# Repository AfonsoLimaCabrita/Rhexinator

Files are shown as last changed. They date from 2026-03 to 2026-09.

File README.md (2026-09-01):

# Rhexinator — 3D-Printed Capsulorhexis Training Simulator

**Rhexinator** is a 3D-printed training model for practicing **continuous curvilinear capsulorhexis (CCC)** mechanics and cataract-style instrument ergonomics using a replaceable **film “capsule”**. The model is designed to provide realistic approach constraints (face/orbit/temporal and superior approach), a repeatable anterior-chamber working space, and **wound-based pivoting** via corneal incisions.

> **License:** CC0-1.0 (public domain dedication)  
> **Intended use:** training/education only (not a medical device)

---

## This project represents a collaborative work by:

- **Ophthalmology department, Unidade Local de Saude Santa Maria**
- **Faculdade de Medicina da Universidade de Lisboa**
- **Ophthalmology department, Unidade Local de Saude Sao Jose**
- **Universidade de Coimbra Faculdade de Medicina**
- **Universidade Nova de Lisboa Medical School**
- **Mass. Eye and Ear**

---

## What’s in this repository

Current printable parts (STL):

- `Face v6.stl` — upper half of the face/orbit housing  
- `Eye support v8.stl` — socket adapter / support that seats in the orbit and clamps the film  
- `Eye v10.stl` — eye module with iris + cornea + corneal incisions  
- `Stick v3.stl` — plunger/stick used to set eye height within the face (exposure/working depth)

---

## Bill of materials

- 3D-printed parts only (no screws required)
- **Consumable film sheet** (capsule surrogate), placed between the support and the eye module

### Film material (capsule surrogate)
Use a **thin, cellofane, flexible craft film sheet** (pre-cut square sheets). It is typically smooth/glossy, compliant under tension, and will generally **propagate a tear from a starter nick**, making it suitable for repeated CCC tear-control practice when clamped evenly.

**Handling tips**
- Aim for **uniform circumferential tension** (no slack/wrinkles over the working zone).
- If initiation is difficult: create a starter nick with a cystotome.

---

## Recommended print materials

- **TPU 95A:**  
  - `Eye v9.stl`  
  - `Eye support v3.stl`

- **PLA:**  
  - `Face v5.stl`  
  - `Plunger v2.stl`

All parts are designed for **friction-fit assembly** (no hardware).

### Baseline print settings (starting points)
These are generic starting points—tune to your printer/material.

### PLA (Face, Stick)
- Layer height: **0.20 mm**
- Perimeters/walls: **2**
- Infill: **15–25%**
- Supports: **None**

### TPU 95A (Eye, Eye support)
- Print speed: **Slow** (TPU-appropriate)
- Layer height: **0.20 mm / 0.08mm (For top surface of Eye support)**
- Seam: **Opposite to corneal incision**
- Surface pattern: **Circular** (all surfaces)
- Perimeters/walls: **4** (for durable edges)
- Retraction: **1.5 mm**
- Supports: **None**
---

## Assembly

### 1) Seat the support in the orbit
- Press `Eye support v3.stl` into the socket area of `Face v5.stl`.

### 2) Place the film (critical)
- Cut a small section of the square sheet of film and lay it **flat over the support**, centered.

### 3) Install the eye module (clamps the film)
- Press `Eye v9.stl` into the support so the film is **captured and tensioned** between:
  - **Support (below)** and **Eye module (above)**

Check that the film is taut across the working zone with minimal wrinkling.

### 4) Set eye height
- Use `Stick v2.stl` (plunger) to adjust the **height of the eye within the face**, tuning exposure/working depth.

---

## How to use (technique notes)

### Corneal incisions
The **rectangular incisions in the cornea** are meant to be used ports:
- Insert cystotome or capsulorhexis forceps through the rectangular ports into the anterior chamber.
- Use the incision edge as a **fulcrum** to pivot the instrument for controlled intra-chamber motion.
- This encourages “operate about the incision” mechanics rather than free-hand motion.

### Suggested practice workflow
1. Load a fresh film sheet.
2. Create a starter flap (needle/cystotome technique).
3. Complete CCC with forceps:
   - maintain smooth tear propagation
   - maintain centration
   - aim for consistent diameter and circularity
4. Replace the film and repeat.

---

## Troubleshooting

**Film wrinkles / inconsistent tension**
- Re-seat the film, ensure it is centered before pressing the eye in.
- Clean the clamping surfaces (dust reduces grip and uniform tension).

**Friction-fit too tight**
- Lightly sand mating surfaces or reduce XY expansion in slicer.
- TPU parts can “grab” PLA; small tolerance tweaks help.

**Friction-fit too loose**
- Increase perimeters or slightly increase extrusion multiplier.
- Consider printing TPU parts at slightly higher flow for a snugger fit (printer-dependent).

---

## Disclaimer

This project is provided **as-is** for training and educational purposes only.  
Not intended for diagnosis, treatment, patient use, or as a regulated medical device.

---

## Citation

If you use this in a presentation or educational work:

> Lima-Cabrita A. *Rhexinator: 3D-Printed Capsulorhexis Training Simulator*. GitHub repository.

---

## License

CC0-1.0 — see `LICENSE`.

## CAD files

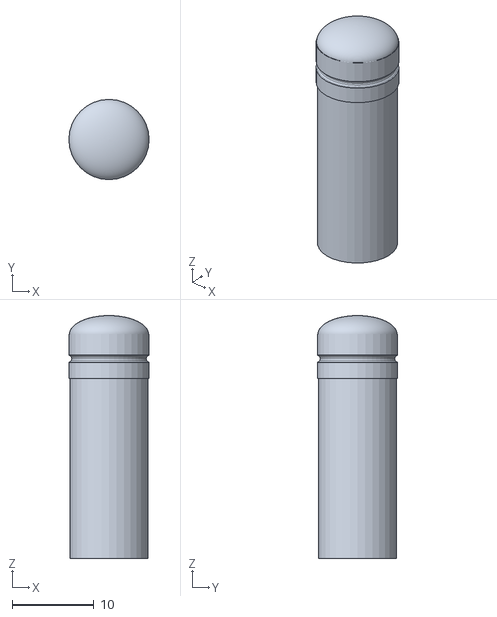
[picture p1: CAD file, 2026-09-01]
Eye support v8.stl
9.80 x 9.80 x 29.7

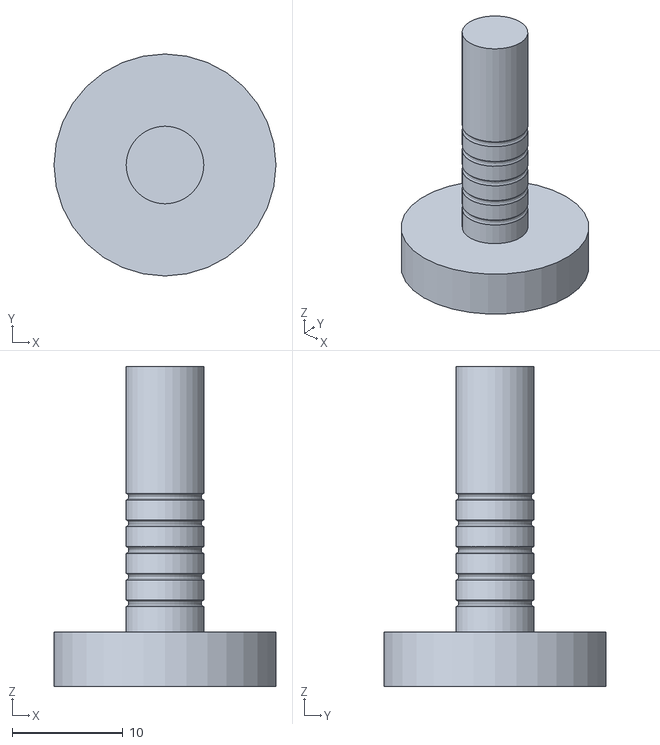
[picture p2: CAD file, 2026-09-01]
Stick v3.stl
20.0 x 20.0 x 28.8

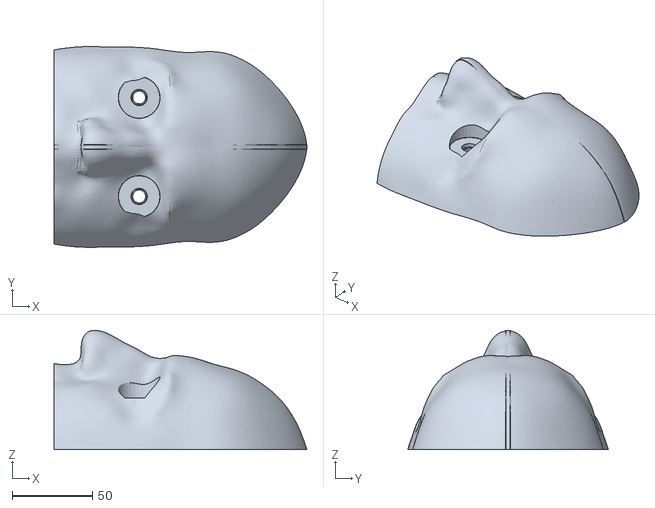
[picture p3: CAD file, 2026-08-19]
Face v6.stl
157.2 x 124.7 x 74.1

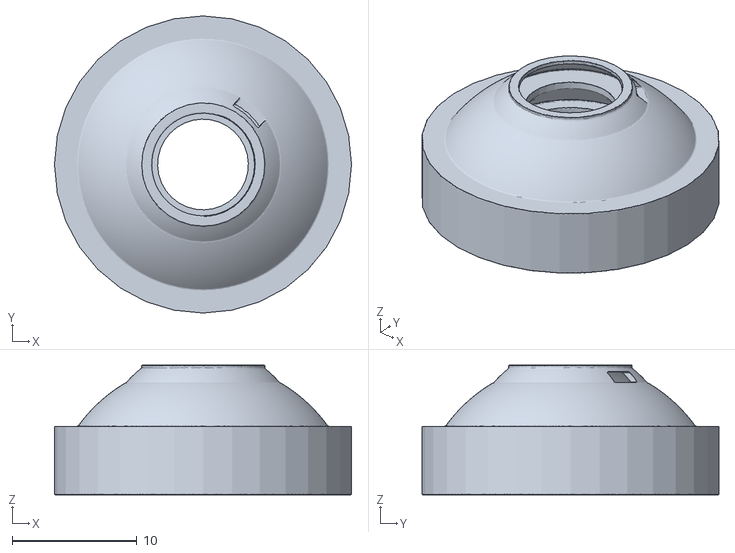
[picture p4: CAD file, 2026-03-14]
Eye v10.stl
23.8 x 23.8 x 10.4

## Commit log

2026-02-26 Revise README for Rhexinator training simulator
    Updated README to provide detailed information about the Rhexinator 3D-printed capsulorhexis training simulator, including assembly instructions, materials, and usage guidelines.
2026-02-26 Rename Stick v2.stl to Plunger v2.stl
    [Plunger v2.stl]
2026-03-14 Add files via upload
    Updated eye. Now with single corneal incision to facilitate printing and lower fit groove. By lowering the groove, there is space between the iris and lens.
    [Eye v10.3mf]
2026-08-19 Update STL file versions in README
